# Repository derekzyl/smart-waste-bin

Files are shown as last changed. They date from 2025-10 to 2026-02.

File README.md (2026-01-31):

# Smart Waste Bin - IoT Waste Management System

A comprehensive IoT-based smart waste bin system that automatically detects material type (organic/non-organic) and manages waste segregation using ESP32 microcontrollers, ESP32-CAM for material detection, and a Flutter mobile app for control and monitoring.

## 🎯 Features

- **Motion Detection**: Automatically detects when someone approaches the bin
- **Material Classification**: Uses ESP32-CAM to classify waste as organic or non-organic
- **Automatic Bin Opening**: Opens the appropriate bin based on material type
- **Bin Level Monitoring**: Tracks bin fill level using ultrasonic sensors and load cells
- **Full Bin Protection**: Prevents opening when bins are full (except via app or keypad)
- **LED Indicators**: Visual feedback for bin status and fill level
- **Dual Communication**: WiFi communication with backend and direct ESP32 communication
- **Mobile App Control**: Full UI control via Flutter app
- **Backend API**: FastAPI backend for material detection and data management
- **Unique Bin IDs**: Each bin has a unique identifier for easy tracking

## 📋 System Architecture

```
┌─────────────────┐
│   Flutter App   │
│  (Mobile/Web)   │
└────────┬────────┘
         │
         ├───────────────────┐
         │                   │
    ┌────▼─────┐      ┌──────▼──────┐
    │  Backend │      │   ESP32     │
    │ (FastAPI)│      │   (Main)    │
    └──────────┘      └──────┬──────┘
                             │
                    ┌────────┴────────┐
                    │                 │
              ┌─────▼─────┐    ┌─────▼─────┐
              │ ESP32-CAM │    │  Sensors  │
              │ (Material │    │ & Actuators│
              │ Detection)│    └───────────┘
              └───────────┘
```

## 🔧 Hardware Components

### Core Components
- **ESP32-WROOM-32** (Main Controller)
- **ESP32-CAM** (Material Detection)
- **HC-SR04 Ultrasonic Sensor** (Distance/Bin Level)
- **Load Cell 5-10kg + HX711** (Weight Measurement)
- **SG90/MG996R Servo Motors** (Lid Control)
- **LEDs** (Red/Green/Blue for Status)
- **Piezo Buzzer** (Audio Feedback)
- **Tactile Buttons** (Keypad)

### Power Management
- **18650 Li-ion Cells** (2x for 7.4V)
- **TP4056 Charging Module**
- **MT3608 Boost Converter**
- **AMS1117-3.3V LDO**

See `smart_bin_design/` for PCB schematics.

## 📁 Project Structure

```
smart-waste-bin/
├── smart_waste_bin_firmware_/     # ESP32 Firmware
│   ├── src/
│   │   ├── main.cpp               # Main ESP32 firmware
│   │   └── esp32cam_main.cpp      # ESP32-CAM firmware
│   └── platformio.ini             # PlatformIO configuration
├── backend/                        # FastAPI Backend
│   ├── main.py                    # Backend API server
│   ├── requirements.txt           # Python dependencies
│   └── README.md                  # Backend documentation
├── smart_bin_app/                 # Flutter Mobile App
│   ├── lib/
│   │   ├── main.dart             # App entry point
│   │   ├── models/               # Data models
│   │   ├── services/             # API services
│   │   ├── providers/            # State management
│   │   ├── screens/              # UI screens
│   │   └── widgets/              # Reusable widgets
│   └── pubspec.yaml              # Flutter dependencies
└── smart_bin_design/              # KiCad PCB Design
```

## 🚀 Getting Started

### 1. ESP32 Firmware Setup

1. Install PlatformIO:
   ```bash
   pip install platformio
   ```

2. Configure WiFi credentials in `smart_waste_bin_firmware_/src/main.cpp`:
   ```cpp
   const char* ssid = "YOUR_WIFI_SSID";
   const char* password = "YOUR_WIFI_PASSWORD";
   const char* backend_url = "http://your-backend-url.com";
   ```

3. Upload firmware to ESP32:
   ```bash
   cd smart_waste_bin_firmware_
   pio run -e esp32dev -t upload
   ```

4. Upload ESP32-CAM firmware:
   ```bash
   pio run -e esp32cam -t upload
   ```

### 2. Backend Setup

1. Install Python dependencies:
   ```bash
   cd backend
   pip install -r requirements.txt
   ```

2. Run the backend server:
   ```bash
   python main.py
   ```
   
   Or with uvicorn:
   ```bash
   uvicorn main:app --host 0.0.0.0 --port 8000 --reload
   ```

3. The API will be available at `http://localhost:8000`
   - API Docs: `http://localhost:8000/docs`

### 3. Flutter App Setup

1. Install Flutter dependencies:
   ```bash
   cd smart_bin_app
   flutter pub get
   ```

2. Configure backend URL in the app settings (or default: `http://192.168.1.100:8000`)

3. Run the app:
   ```bash
   flutter run
   ```

## 📡 Communication Protocols

### ESP32 ↔ ESP32-CAM (CAN/TWAI)
- ESP32 sends: `DETECT_MATERIAL` request
- ESP32-CAM responds: `MATERIAL:ORGANIC` or `MATERIAL:NON_ORGANIC`

### ESP32 ↔ Backend (HTTP)
- POST `/api/bins/update` - Update bin status
- GET `/api/bins` - Get all bins status

### ESP32 ↔ Flutter App (WebSocket)
- Real-time bin status updates
- Commands: `open_organic`, `open_non_organic`, `close_*`, `get_status`

### ESP32-CAM ↔ Backend (HTTP)
- POST `/api/detect` - Material detection with image upload

## 🔌 Pin Configuration

### ESP32 Main Controller
### ESP32 Main Controller
- **Presence Ultrasonic**: TRIG=GPIO 4, ECHO=GPIO 5
- **Organic Level Ultrasonic**: TRIG=GPIO 25, ECHO=GPIO 26
- **Inorganic Level Ultrasonic**: TRIG=GPIO 32, ECHO=GPIO 33
- **Servos**: Organic=GPIO 18, Non-Organic=GPIO 19
- **Load Cell**: DOUT=GPIO 16, SCK=GPIO 17
- **LEDs Organic**: Red=GPIO 27, Green=GPIO 14
- **LEDs Inorganic**: Red=GPIO 12, Green=GPIO 13
- **Buzzer**: GPIO 15
- **Keypad**: Button1=GPIO 23, Button2=GPIO 2 (reassigned due to PIR removal)
- **CAN**: TX=GPIO 21, RX=GPIO 22

## 🎮 Usage

### Automatic Mode
1. Person approaches bin (PIR detects motion)
2. ESP32-CAM captures image and classifies material
3. Appropriate bin opens automatically
4. Bin closes after motion timeout

### Manual Mode (App/Keypad)
- Use Flutter app to open/close bins manually
- Use keypad buttons for quick access
- Maintenance mode available via app

### Bin Full Protection
- When bin reaches 90% capacity, it cannot be opened automatically
- Bins can still be opened via app or keypad for maintenance
- LED indicators show bin status (Red=Full, Yellow=High, Green=Normal)

## 🔐 Security & Configuration

- WiFi credentials stored in firmware 
- Backend API endpoints can be secured with authentication
- Bin IDs are unique identifiers for tracking

## 🧪 Testing

1. **Hardware Testing**: Test each sensor individually before full integration
2. **Material Detection**: Test with various waste types to improve classification
3. **Network Testing**: Verify WiFi connectivity and backend communication
4. **App Testing**: Test all app features on both WiFi and direct ESP32 connection

## 🤝 Contributing

1. Fork the repository
2. Create a feature branch
3. Make your changes
4. Submit a pull request

## 📄 License

This project is open source and available for educational and commercial use.

## 🙏 Acknowledgments

- ESP32 platform
- FastAPI framework
- Flutter framework
- OpenCV for image processing

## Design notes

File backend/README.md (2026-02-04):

# Smart Waste Bin Backend API

FastAPI backend for material detection and bin management with advanced image recognition.

## Features

- **Advanced Image Recognition**: Computer vision and ML-based material classification
- **Multiple Classification Methods**: ML model or rule-based fallback
- **Feature Extraction**: Comprehensive feature analysis (color, texture, shape, edges)
- **Model Training**: Script to train custom models on your data
- **RESTful API**: Easy-to-use endpoints for all operations

## Installation

```bash
pip install -r requirements.txt
```

## Running

```bash
python main.py
```

Or with uvicorn for development:

```bash
uvicorn main:app --host 0.0.0.0 --port 8000 --reload
```

The API will be available at `http://localhost:8000`
- API Docs: `http://localhost:8000/docs`
- Alternative Docs: `http://localhost:8000/redoc`

## Image Recognition System

### How It Works

The system uses a multi-feature approach for material classification:

1. **Color Analysis**: HSV color space, color histograms, dominant colors
2. **Texture Analysis**: Local Binary Patterns (LBP) for texture features
3. **Edge Detection**: Canny edge detection for shape analysis
4. **Contour Analysis**: Shape and circularity measurements
5. **Color Distribution**: Organic vs non-organic color indicators
6. **Color Diversity**: Entropy-based color variation analysis

### Classification Methods

#### 1. Machine Learning Model (Recommended)
- Uses Random Forest classifier
- Trained on labeled data
- Higher accuracy
- Requires training data

#### 2. Rule-Based Classifier (Default)
- Works out of the box
- No training required
- Good baseline accuracy
- Based on color and texture heuristics

### Training a Custom Model

1. **Prepare Training Data**:
   ```
   training_data/
     organic/
       image1.jpg
       image2.jpg
       ...
     non_organic/
       image1.jpg
       image2.jpg
       ...
   ```

2. **Run Training Script**:
   ```bash
   python train_model.py
   ```

3. **Use Trained Model**:
   - Set environment variable: `export MODEL_PATH=models/material_classifier.pkl`
   - Or update `main.py` to use the model path

## API Endpoints

### Material Detection

**POST** `/api/detect`
- Accepts: JPEG image file
- Returns: Classification result with material type and confidence

Example:
```bash
curl -X POST "http://localhost:8000/api/detect" \
  -F "file=@waste_image.jpg"
```

Response:
```json
{
  "material": "ORGANIC",
  "confidence": 0.85,
  "method": "ml_model",
  "probabilities": {
    "organic": 0.85,
    "non_organic": 0.15
  }
}
```

### Bin Management

- `GET /api/bins` - Get all bins status
- `GET /api/bins/{bin_id}` - Get specific bin status
- `POST /api/bins/update` - Update bin status from ESP32
- `POST /api/bins/{bin_id}/reset` - Reset bin (maintenance)
- `GET /api/stats` - Get overall statistics

## Configuration

### Environment Variables

- `MODEL_PATH`: Path to trained model file (default: `models/material_classifier.pkl`)
- `PORT`: Server port (default: 8000)
- `HOST`: Server host (default: 0.0.0.0)

### Model Performance

- **Rule-based**: ~70-75% accuracy
- **ML Model (trained)**: ~85-95% accuracy (depends on training data quality)

## Improving Accuracy

1. **Collect More Training Data**: More diverse images = better accuracy
2. **Image Quality**: Ensure good lighting and focus in training images
3. **Data Balance**: Equal number of organic and non-organic samples
4. **Augmentation**: Use data augmentation for better generalization
5. **Feature Engineering**: Add domain-specific features if needed

## Production Considerations

1. **Database**: Replace in-memory storage with PostgreSQL/MongoDB
2. **Model Versioning**: Track model versions and performance
3. **Caching**: Cache classification results for similar images
4. **Monitoring**: Add logging and performance monitoring
5. **Security**: Add authentication and rate limiting
6. **GPU Support**: Use GPU-accelerated TensorFlow for faster inference

## Troubleshooting

**Model not loading?**
- Check model file path
- Ensure joblib is installed
- Verify model file format

**Low accuracy?**
- Collect more training data
- Improve image quality
- Check for class imbalance
- Try different features or models

**Slow inference?**
- Use GPU acceleration
- Reduce image size
- Optimize feature extraction
- Use model quantization
# waste-bin-backend

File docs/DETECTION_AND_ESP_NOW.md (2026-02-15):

# Detection flow, app display, and ESP-NOW

## 1. Does the app show when someone opens a bin and the material?

**Yes**, when the conditions below are met.

### When the app is connected to the device (Settings → ESP32 IP set)

- The main ESP32 sends **WebSocket** messages to the app: `DETECTION_EVENT` with `action` and `material`/`confidence`.
- The app shows a **banner** at the top of the home screen:
  - **"Analyzing material..."** (orange, with spinner) while the bin is analyzing.
  - **"Organic (95%) — Opening bin"** or **"Non-organic (95%) — Opening bin"** (green) when a bin is opening, with the detected material and confidence.
  - **"Closing bin"** (grey) when the lid is closing.
- The banner hides automatically after about 4 seconds.
- So you do see **when** a bin is opening and **what material** was detected (organic vs non-organic and confidence %).

### When the app is not connected to a device (simulation / backend only)

- The app polls **`/api/detections?limit=1`** every 3 seconds and can show the **last detection** from the backend (material/confidence).
- When you tap **Open** (Organic or Non-organic), the app shows the same **"… — Opening bin"** banner for that choice.
- So in simulation you still see “opening” and “material” for the last detection and for manual open.

---

## 2. Why ESP-NOW might not work between ESP32-CAM and main devkit

ESP-NOW works only when both radios are on the **same 2.4 GHz channel** and addressing is correct. Typical causes of failure:

### A. WiFi channel mismatch (most common)

- **Main devkit**: Connects to WiFi (e.g. "cybergenii") and gets a channel (e.g. 6). It adds the CAM as peer with `channel = 0` (“use my current channel”).
- **ESP32-CAM**: Also uses STA mode. If it **connects to the same AP**, it usually gets the same channel and ESP-NOW can work. If it **doesn’t connect** (wrong password, no network, timeout), it may stay on a default channel (e.g. 1). Then:
  - Main sends on channel 6, CAM listens on channel 1 → **CAM never receives** → no trigger, no pairing.
  - So the first packet (Main → CAM) never arrives, and the CAM never learns the Main’s MAC to send the result back.

**What to do:** Ensure both devices use the same channel. E.g.:

- Confirm both connect to the same WiFi and check `WiFi.channel()` in Serial on both.
- Or set a fixed channel on both (e.g. `WiFi.begin(ssid, password, channel)` and use that same channel in `esp_now_peer_info_t.peer_info.channel` when adding the peer).

### B. Wrong ESP32-CAM MAC on the main

- The **main** has a **hardcoded** CAM MAC: `A0:DD:6C:AF:09:30` (in `main.cpp`).
- If your ESP32-CAM has a different MAC (different board, reflashed module), the main is sending to the wrong address and the CAM never receives.

**What to do:** On the ESP32-CAM, print its MAC at boot (e.g. `Serial.println(WiFi.macAddress());`). Update `camMacAddress[]` in the main firmware to that MAC.

### C. CAM never receives the first packet (so it never “pairs”)

- The **CAM** does **not** know the main’s MAC at compile time. It learns it only when it **receives** an ESP-NOW command (e.g. "DETECT") from the main and then adds that sender as a peer.
- If the main’s ESP-NOW send **fails** (channel/MAC as above), the CAM never receives, so:
  - `mainControllerRegistered` stays false,
  - When the CAM later runs detection (e.g. via **GPIO trigger**), it tries to send the result to an uninitialized or wrong MAC and **ESP-NOW send fails**.

So ESP-NOW can appear to “not work” in both directions: Main→CAM (trigger) and CAM→Main (result), often due to that first Main→CAM packet never arriving.

### D. Power / antenna

- ESP32-CAM can be power-hungry. Brown-out or unstable power can cause WiFi/ESP-NOW to fail.
- Poor antenna or metal enclosure can reduce range and make links unreliable.

### Summary

- **Most likely:** Channel mismatch (CAM not on same channel as main) or wrong CAM MAC on the main.
- **Check:** Serial on both sides: main “ESP-NOW Send Status: ✅/❌”, CAM “ESP-NOW Command Received” (or not), and `WiFi.channel()` on both. Fix channel and MAC first; then re-test.

---

## 3. How does polling work when an object is detected?

High-level flow:

1. **Presence**
   - Main ESP32 sees someone (ultrasonic presence sensor).
   - State goes **IDLE → DETECTING_MOTION**.

2. **Trigger camera**
   - Next loop: **DETECTING_MOTION → ANALYZING_MATERIAL**.
   - Main sends **"DETECT"** to the CAM via **ESP-NOW** and toggles **GPIO** (backup).
   - Main broadcasts **"ANALYZING"** on WebSocket so the app can show “Analyzing material...”.

3. **Camera and backend**
   - CAM captures image (triggered by ESP-NOW or GPIO).
   - CAM sends image to backend **POST /api/detect** (HTTPS).
   - Backend runs the classifier (e.g. Gemini), returns ORGANIC or NON_ORGANIC/INORGANIC, and **queues an OPEN command** in the DB for bin `0x001` (organic) or `0x002` (non-organic).

4. **Polling (main ESP32)**
   - While in **ANALYZING_MATERIAL**, the main ESP32 polls **every 100 ms** with a **single** request:
     - `GET /api/bins/commands` (returns pending commands for both bins).
   - Uses **HTTPS** (WiFiClientSecure).
   - Backend returns any pending commands for that bin and **removes** them from the queue (poll-once semantics).

5. **When OPEN is in the response**
   - Main parses the JSON (e.g. `command: "OPEN"`, `params: { material, confidence }`).
   - Main sets:
     - `currentState = OPENING_BIN`
     - `selectedBin = 0x001` or `0x002`
     - `openFromBackendCommand = true` (so the bin opens even if level sensors say “full”).
   - Main broadcasts **"OPENING"** on WebSocket with material and confidence so the app can show “Organic (95%) — Opening bin” (or non-organic).

6. **Opening the bin**
   - On the next loop iteration, the state machine runs **OPENING_BIN**:
     - Calls `openBin(0)` or `openBin(1)` (servo).
     - State goes to **BIN_OPEN** (lid stays open for a while, then auto-closes).

So **polling** is: the main MCU repeatedly asks the backend “any OPEN/CLOSE for 0x001 / 0x002?” every 250 ms while it’s waiting for the result. As soon as the backend has classified the image and queued OPEN, the next poll returns that command and the main opens the bin and notifies the app. No ESP-NOW or UART is required for this path.

---

## 4. Where does detection-to-open time go? (Latency)

| Phase | Typical time | Notes |
|---|---|---|
| Presence to trigger | 0–100 ms | Presence check every 100 ms. |
| Main to CAM trigger | 1–50 ms | ESP-NOW or GPIO. |
| **CAM capture + upload** | **0.5–2 s** | JPEG encode + HTTPS POST. |
| **Backend inference** | **1–4+ s** | Cloud API; usually the **largest** part. |
| Backend to queue | &lt; 50 ms | DB write. |
| Main polls and gets OPEN | 0–100 ms | Poll every 100 ms; single HTTPS GET. |
| Servo open | 50–200 ms | Physical. |

Most lag is **backend inference** and **image upload**. To reduce further: smaller image, faster model, or local inference.

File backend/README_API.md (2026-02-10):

# Energy Audit Backend API

## Overview
FastAPI extension for the Smart Energy Auditing System.
Integrated into the existing `smart-waste-bin` backend.

## New Endpoints (`/energy/...`)
-   `POST /energy/readings`: Accept sensor data from ESP32.
-   `GET /energy/readings/{id}`: Get stored readings.
-   `GET /energy/audit/{id}/alerts`: Get generated waste alerts.
-   `POST /energy/devices`: Register new devices.

## Setup
1.  Navigate to `backend/`.
2.  Install dependencies (if not already): `pip install -r requirements.txt`.
3.  Run Server:
    ```bash
    uvicorn main:app --reload --host 0.0.0.0
    ```
4.  Swagger Docs: `http://localhost:8000/docs`.

## Database
-   Tables `energy_devices`, `energy_sensor_readings`, etc., are created on startup.
-   Uses SQLite/PostgreSQL as configured in `database.py`.

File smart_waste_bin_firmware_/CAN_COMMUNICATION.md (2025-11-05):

# CAN Communication Guide

## Overview

The ESP32 and ESP32-CAM communicate via CAN (Controller Area Network) using ESP32's TWAI (Two-Wire Automotive Interface) protocol.

## Implementation Note

The current firmware uses simplified CAN message stubs. For production, you need to implement proper TWAI communication.

## Required Library

Add to `platformio.ini`:
```ini
lib_deps = 
    esp32-idf/twai
```

## CAN Message Format

### Request from ESP32 to ESP32-CAM
- **ID**: `0x100`
- **Data**: `"DETECT_MATERIAL"`
- **Purpose**: Request material detection

### Response from ESP32-CAM to ESP32
- **ID**: `0x200`
- **Data**: `"MATERIAL:ORGANIC"` or `"MATERIAL:NON_ORGANIC"` or `"MATERIAL:UNKNOWN"`
- **Purpose**: Send detection result

## Example TWAI Implementation

```cpp
#include "driver/twai.h"

void setupCAN() {
    twai_general_config_t g_config = TWAI_GENERAL_CONFIG_DEFAULT(
        GPIO_NUM_21,  // TX
        GPIO_NUM_22,  // RX
        TWAI_MODE_NORMAL
    );
    twai_timing_config_t t_config = TWAI_TIMING_CONFIG_500KBITS();
    twai_filter_config_t f_config = TWAI_FILTER_CONFIG_ACCEPT_ALL();
    
    ESP_ERROR_CHECK(twai_driver_install(&g_config, &t_config, &f_config));
    ESP_ERROR_CHECK(twai_start());
}

void sendCANMessage(uint32_t id, String message) {
    twai_message_t tx_msg;
    tx_msg.identifier = id;
    tx_msg.data_length_code = message.length();
    for (int i = 0; i < message.length() && i < 8; i++) {
        tx_msg.data[i] = message[i];
    }
    tx_msg.flags = TWAI_MSG_FLAG_NONE;
    twai_transmit(&tx_msg, pdMS_TO_TICKS(1000));
}

bool receiveCANMessage(uint32_t* id, String* message) {
    twai_message_t rx_msg;
    if (twai_receive(&rx_msg, pdMS_TO_TICKS(100)) == ESP_OK) {
        *id = rx_msg.identifier;
        *message = "";
        for (int i = 0; i < rx_msg.data_length_code; i++) {
            *message += (char)rx_msg.data[i];
        }
        return true;
    }
    return false;
}
```

## Testing

1. Connect ESP32 and ESP32-CAM via CAN bus (with proper termination resistors)
2. Test message transmission/reception
3. Verify material detection communication

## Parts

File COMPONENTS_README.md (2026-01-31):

# Smart Waste Bin - Components Reference

## Microcontrollers & Core Processing

### ESP32-WROOM-32
Main microcontroller that handles motion detection, sensor readings, servo control, WiFi communication, and system coordination.

### ESP32-CAM Module
Dedicated camera module that captures images for material classification and communicates detection results via CAN bus.

### USB-C or Micro-USB Breakout
Provides power input and programming interface for ESP32 development and firmware updates.

---

## Sensors

### HC-SR04 Ultrasonic Sensor (Presence Detection)
Replaces the PIR sensor to detect when a person is approaching the bin to trigger the system.

### JSN-SR04T Waterproof Ultrasonic Sensor (x2)
Two waterproof sensors used to measure the fill levels of the Organic and Non-Organic bins independently.

### Load Cell (5kg or 10kg)
Measures the weight of waste in the bin using strain gauge technology.

### HX711 Load Cell Amplifier Module
Amplifies and converts analog load cell signals into digital data readable by the ESP32.

---

## Actuators & Feedback

### MG996R Servo Motor (Alternative)
Heavy-duty servo motor capable of handling bin lids up to 1.5kg with higher torque.

### 5mm LED (2x Red, 2x Green)
- **2x Red**: Indicate when the Organic or Non-Organic bin is full.
- **2x Green**: Indicate that the Organic or Non-Organic bin has space available.

### Piezo Buzzer (Active 3-5V)
Provides audio feedback for bin operations, alerts, and warnings.

### Tactile Push Button (6×6mm)
Manual override buttons for opening bins when automatic system is unavailable or for maintenance.

---

## Power Management

### 18650 Li-ion Cell (3000-3500mAh)
Rechargeable battery cells providing 3.7V power source for portable operation.

### MT3608 Boost Converter (2A, Adjustable)
Steps up battery voltage to 5V for powering servos and other 5V components.

### XL6009 Boost Module (Alternative)
Alternative boost converter module with higher current capacity for power-hungry applications.

### AMS1117-3.3V LDO Regulator
Provides stable 3.3V power supply for ESP32 and other low-voltage components from higher voltage sources.

### Mini360 Buck Converter (Alternative)
DC-DC step-down converter alternative for efficiently reducing voltage to 3.3V.

---

## Circuit Components

### Capacitors

#### 0.1µF (100nF) Ceramic Capacitor (X7R, 50V) - 6 pcs
Decoupling capacitors that filter high-frequency noise from power supply lines to prevent interference.

#### 1µF Ceramic Capacitor (X7R, 50V) - 3 pcs
Filters noise and stabilizes voltage for analog sensor inputs.

#### 10µF Ceramic Capacitor (X5R/X7R, 25V) - 2 pcs
Provides output stability for voltage regulators and prevents oscillation.

#### 100µF Electrolytic Capacitor (Low-ESR, 25V) - 2 pcs
Bulk capacitance that smooths power supply fluctuations and handles current surges.

#### 470µF Electrolytic Capacitor (Low-ESR, 16V) - 1 pc
Optional motor surge protection capacitor that absorbs voltage spikes from servo operation.

### Resistors (1/4W, 5% tolerance)

#### 10kΩ Resistor - 5 pcs
Pull-up resistors for digital inputs like buttons and I2C communication lines.

#### 330Ω Resistor - 3 pcs
Current-limiting resistors that protect LEDs from excessive current draw.

#### 4.7kΩ Resistor - 2 pcs
I2C bus pull-up resistors for reliable communication with external modules.

### Other Passive Components

#### Ferrite Bead (600Ω @ 100MHz) - 2 pcs
Filters electromagnetic interference from power supply lines to reduce noise.

#### Schottky Diode 1N5819 (1A) - 2 pcs
Provides reverse polarity protection and flyback diode protection for servo motors.

---

## Connectors & Wiring

### JST-XH 2.54mm Connectors (2-pin, 3-pin, 4-pin)
Standardized connectors for reliable, removable connections between PCBs and components.

### DuPont Jumper Wires (M-M, M-F, F-F)
Flexible prototyping wires for connecting components during development and testing.

### 22 AWG Silicone Wire (Red/Black) - 2m each
Flexible power and ground wires with high-temperature resistance for permanent installations.

### Heat Shrink Tubing (Assorted Sizes)
Protective insulation that shrinks when heated to secure and insulate wire connections.

---

## Enclosure & Mechanical

### Servo Horn/Arm
Attaches to servo motor shaft to connect with bin lid mechanism for opening/closing action.

### M2/M3 Screws and Nuts
Hardware for assembling the physical structure and mounting components securely.

### Plastic Hinges (Small)
Allows bin lids to pivot smoothly when opened and closed by servo motors.

### Cable Glands or Grommets (6-10mm)
Provides waterproof cable entry points in the enclosure for outdoor installations.

---

## Optional Add-ons

### SIM800L GSM Module
Enables SMS alerts and remote monitoring without WiFi connection using cellular network.

### PN532 NFC/RFID Reader Module
Adds access control functionality for authorized users via NFC cards or RFID tags.

### 6V 1W Solar Panel + TP4056 Solar Charge Controller
Provides renewable energy charging for outdoor installations with sunlight exposure.

---

## Component Summary by Category

| Category | Component Count | Purpose |
|---|---|---|
| Microcontrollers | 2 | System control and processing |
| Sensors | 5 | Detection and measurement |
| Actuators | 5 | Movement and feedback |
| Power Management | 6 | Battery and power regulation |
| Passive Components | ~20 | Circuit protection and filtering |
| Connectors | Assorted | Interconnections |
| Mechanical | Assorted | Physical assembly |

---

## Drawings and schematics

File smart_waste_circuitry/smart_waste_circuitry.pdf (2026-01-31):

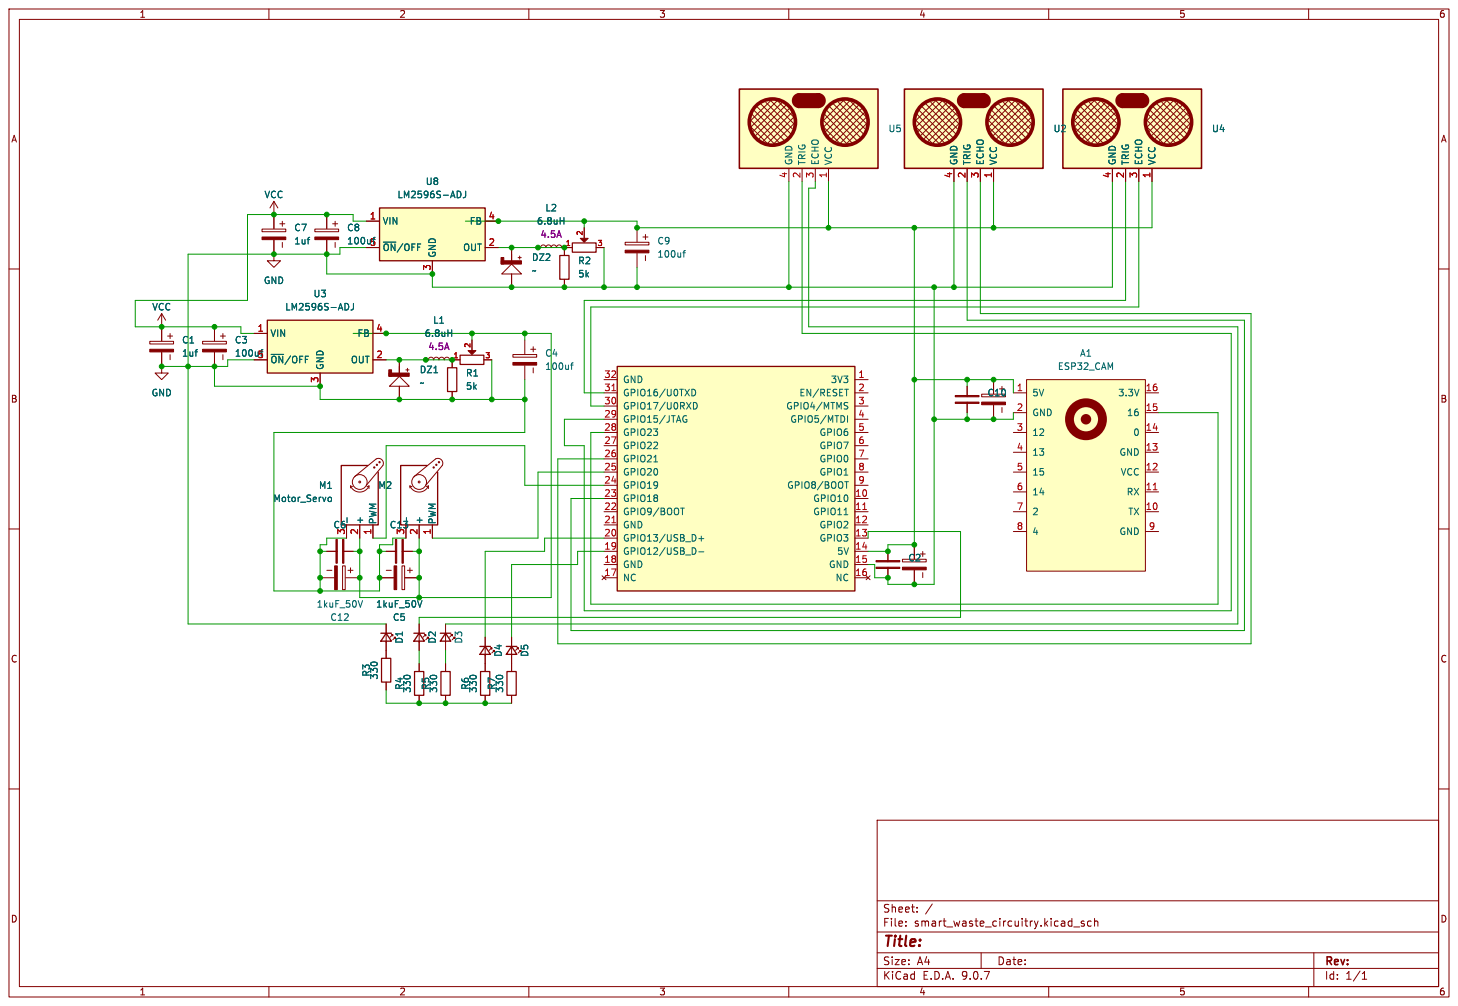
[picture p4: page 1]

Id: 1/1 Title: File: smart_waste_circuitry.kicad_sch Sheet: /

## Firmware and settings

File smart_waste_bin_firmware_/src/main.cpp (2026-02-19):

/**
 * ESP32 Smart Waste Bin - ESP-NOW CONNECTION FIX
 * ESP32-CAM MAC: A0:DD:6C:AF:09:30
 */

#include <Arduino.h>
#include <WiFi.h>
#include <esp_now.h>
#include <ESPAsyncWebServer.h>
#include <ArduinoJson.h>
#include <Adafruit_PWMServoDriver.h> // REPLACES ESP32Servo
#include <WebSocketsServer.h>
#include <HTTPClient.h>
#include <WiFiClientSecure.h>

// ==================== PIN DEFINITIONS ====================
#define TRIG_PIN_PRESENCE 32
#define ECHO_PIN_PRESENCE 34
#define TRIG_PIN_ORG 33
#define ECHO_PIN_ORG 35
#define TRIG_PIN_INORG 13
#define ECHO_PIN_INORG 36



// PCA9685 SERVO CONFIG
#define SERVOMIN  150 // This is the 'minimum' pulse length count (out of 4096)
#define SERVOMAX  600 // This is the 'maximum' pulse length count (out of 4096)
#define USMIN  600 // This is the rounded 'minimum' microsecond length based on the minimum pulse of 150
#define USMAX  2400 // This is the rounded 'maximum' microsecond length based on the maximum pulse of 600
#define SERVO_FREQ 50 // Analog servos run at ~50 Hz updates

// Channels on PCA9685 (0 to 15)
#define PCA_CHANNEL_ORG 0
#define PCA_CHANNEL_INORG 1

// I2C Pins for PCA9685
#define I2C_SDA 21
#define I2C_SCL 22

#define CAM_TRIGGER_PIN 4

#define LED_ORG_RED_PIN 25
#define LED_ORG_GREEN_PIN 26
#define LED_INORG_RED_PIN 27
#define LED_INORG_GREEN_PIN 14

#define UART_RX_PIN 15
#define UART_BAUD 115200

// ==================== CONFIGURATION ====================
const char* ssid = "cybergenii";
const char* password = "12341234";
const char* backend_url = "https://xenophobic-netta-cybergenii-1584fde7.koyeb.app";
const char* local_access_password = "SmartBin2025";

const char* BIN_ORGANIC_ID = "0x001";
const char* BIN_NON_ORGANIC_ID = "0x002";
const float MAX_BIN_HEIGHT_CM = 91.44;  // 3 feet
const float BIN_FULL_THRESHOLD_CM = 10.0;
const float SENSOR_OFFSET_CM = 5.0;

// ==================== ESP-NOW CONFIGURATION ====================
// ESP32-CAM MAC Address: A0:DD:6C:AF:09:30
uint8_t camMacAddress[] = { 
  0xA0, 0xDD, 0x6C, 0xAF, 0x09, 0x30 
};

bool espNowInitialized = false;
bool camPeerAdded = false;
int espNowSendCount = 0;
int espNowReceiveCount = 0;
int espNowFailCount = 0;

// ESP-NOW Message Structures
typedef struct {
  char command[32];
  unsigned long timestamp;
} CommandMessage;

typedef struct {
  char material[32];
  float confidence;
  unsigned long timestamp;
} DetectionResult;

// ==================== GLOBAL VARIABLES ====================
Adafruit_PWMServoDriver pwm = Adafruit_PWMServoDriver(); // Default address 0x40

// ==================== NEWPING SENSOR SETUP ====================
#include <NewPing.h>

#define MAX_DISTANCE 200 // Maximum distance we want to ping for (in centimeters).

// Sensor Objects
NewPing sonarPresence(TRIG_PIN_PRESENCE, ECHO_PIN_PRESENCE, MAX_DISTANCE);
NewPing sonarOrganic(TRIG_PIN_ORG, ECHO_PIN_ORG, MAX_DISTANCE);
NewPing sonarInorganic(TRIG_PIN_INORG, ECHO_PIN_INORG, MAX_DISTANCE);

// Helper to get median distance (filters noise)
float getFilteredDistance(NewPing &sonar) {
  unsigned int uS = sonar.ping_median(5); // Take 5 readings and return median
  float dist = sonar.convert_cm(uS);
  if (dist == 0) return -1.0; // Timeout or out of range
  return dist;
}

AsyncWebServer server(80);
WebSocketsServer webSocket(81);

enum BinState {
  IDLE,
  DETECTING_MOTION,
  ANALYZING_MATERIAL,
  OPENING_BIN,
  BIN_OPEN,
  CLOSING_BIN
};

BinState currentState = IDLE;
String selectedBin = "";

float organicBinLevelCm = 0.0;
float nonOrganicBinLevelCm = 0.0;
int organicBinLevelPct = 0;
int nonOrganicBinLevelPct = 0;
bool isOrganicBinFull = false;
bool isNonOrganicBinFull = false;

unsigned long lastMotionTime = 0;
unsigned long binOpenTime = 0;
const unsigned long MOTION_TIMEOUT = 5000;
const unsigned long BIN_OPEN_TIMEOUT = 10000;
unsigned long lastLevelCheckTime = 0;
const unsigned long LEVEL_CHECK_INTERVAL = 2000;

unsigned long lastBackendSyncTime = 0;
const unsigned long BACKEND_SYNC_INTERVAL = 5000;
unsigned long lastCommandPollTime = 0;
const unsigned long COMMAND_POLL_INTERVAL = 800;   // Normal: poll every 800ms
const unsigned long COMMAND_POLL_FAST_MS = 100;    // When analyzing: poll every 100ms for low latency

const float PRESENCE_THRESHOLD_CM = 50.0;
const int PRESENCE_DEBOUNCE_COUNT = 3;

String detectedMaterial = "";
float detectedConfidence = 0.0;
bool materialDetectionComplete = false;
unsigned long materialDetectionStartTime = 0;
const unsigned long MATERIAL_DETECTION_TIMEOUT = 15000;  // Increased to 15s

bool presenceDetectedForChase = false;
unsigned long lastChaseUpdate = 0;
const unsigned long CHASE_SPEED = 100;
int chasePosition = 0;

// When true, OPENING_BIN will open the bin even if level sensors say "full" (backend command)
bool openFromBackendCommand = false;
const int LED_PINS[] = {LED_ORG_GREEN_PIN, LED_ORG_RED_PIN, LED_INORG_GREEN_PIN, LED_INORG_RED_PIN};
const int NUM_LEDS = 4;

// ==================== FUNCTION DECLARATIONS ====================
void setupWiFi();
void setupESPNow();
void setupWebServer();
void setupWebSocket();
void setupUART();
void openBin(uint8_t binType);
void closeBin(uint8_t binType);
void updateBinLevels();
void updateLEDs();
void sendBinDataToBackend();
void webSocketEvent(uint8_t num, WStype_t type, uint8_t * payload, size_t length);

void triggerCameraDetection();
void processUARTData();
bool authenticateRequest(AsyncWebServerRequest *request);
void sendWebSocketStatus(uint8_t clientNum);
void handleWebSocketMessage(uint8_t clientNum, String message);
void runLEDChaseMode();
void testAllLEDs();
void testAllSensors();
void onDataRecv(const uint8_t *mac, const uint8_t *incomingData, int len);
void onDataSent(const uint8_t *mac, esp_now_send_status_t status);
void sendESPNowCommand(const char* cmd);
void sendESPNowCommand(const char* cmd);
void testESPNowConnection();
void pollBackendCommands();
int angleToPulse(int angle);
void setServoAngle(uint8_t channel, int angle);
void broadcastDetectionEvent(String material, float confidence, String action);

// ==================== SETUP ====================
void setup() {
  Serial.begin(115200);
  delay(2000);

  Serial.println("\n\n=================================");
  Serial.println("ESP32 Main Controller");
  Serial.println("ESP-NOW + Waterproof Sensors");
  Serial.println("=================================");

  // Initialize pins
  pinMode(TRIG_PIN_PRESENCE, OUTPUT);
  pinMode(ECHO_PIN_PRESENCE, INPUT);
  pinMode(TRIG_PIN_ORG, OUTPUT);
  pinMode(ECHO_PIN_ORG, INPUT);
  pinMode(TRIG_PIN_INORG, OUTPUT);
  pinMode(ECHO_PIN_INORG, INPUT);

  pinMode(LED_ORG_RED_PIN, OUTPUT);
  pinMode(LED_ORG_GREEN_PIN, OUTPUT);
  pinMode(LED_INORG_RED_PIN, OUTPUT);
  pinMode(LED_INORG_GREEN_PIN, OUTPUT);

  pinMode(CAM_TRIGGER_PIN, OUTPUT);
  digitalWrite(CAM_TRIGGER_PIN, LOW);

  pinMode(CAM_TRIGGER_PIN, OUTPUT);
  digitalWrite(CAM_TRIGGER_PIN, LOW);

  // Initialize I2C for PCA9685
  Wire.begin(I2C_SDA, I2C_SCL);
  
  // Initialize PCA9685
  Serial.println("Initializing PCA9685 Servo Controller on 0x40...");
  pwm.begin();
  pwm.setOscillatorFrequency(27000000);
  pwm.setPWMFreq(SERVO_FREQ);  // Analog servos run at ~50 Hz updates
  delay(10);

  // Reset Servos (Close)
  setServoAngle(PCA_CHANNEL_ORG, 0);
  setServoAngle(PCA_CHANNEL_INORG, 0);

  // LED TEST
  Serial.println("\n>>> LED TEST <<<");
  testAllLEDs();

  // Initialize WiFi FIRST (required for ESP-NOW)
  setupWiFi();

  // CRITICAL: WiFi must be initialized before ESP-NOW
  if (WiFi.status() == WL_CONNECTED || WiFi.getMode() == WIFI_STA) {
    setupESPNow();
  } else {
    Serial.println("⚠️  WiFi not initialized - ESP-NOW may fail");
    // Force WiFi STA mode
    WiFi.mode(WIFI_STA);
    WiFi.disconnect();
    delay(100);
    setupESPNow();
  }

  // SENSOR TEST
  Serial.println("\n>>> SENSOR TEST <<<");
  testAllSensors();

  // Test ESP-NOW connection
  Serial.println("\n>>> ESP-NOW CONNECTION TEST <<<");
  testESPNowConnection();

  setupUART();
  setupWebServer();
  setupWebSocket();

  Serial.println("\n=================================");
  Serial.println("SYSTEM READY");
  Serial.println("=================================");
  
  Serial.print("ESP32 Main MAC: ");
  Serial.println(WiFi.macAddress());
  
  Serial.print("ESP32-CAM MAC: ");
  for (int i = 0; i < 6; i++) {
    Serial.printf("%02X", camMacAddress[i]);
    if (i < 5) Serial.print(":");
  }
  Serial.println();
  
  Serial.print("Local IP: ");
  Serial.println(WiFi.localIP());
  
  Serial.println("\n📡 ESP-NOW Status:");
  Serial.println("  Initialized: " + String(espNowInitialized ? "✅" : "❌"));
  Serial.println("  Peer Added: " + String(camPeerAdded ? "✅" : "❌"));
  Serial.println("  WiFi Channel: " + String(WiFi.channel()));
  
  Serial.println("\n🔍 Waiting for presence detection...");
  Serial.println("=================================\n");

  updateLEDs();
}

// ==================== ESP-NOW SETUP ====================
void setupESPNow() {
  Serial.println("\nInitializing ESP-NOW...");
  
  // Ensure WiFi is in STA mode
  if (WiFi.getMode() != WIFI_STA) {
    Serial.println("  Setting WiFi to STA mode...");
    WiFi.mode(WIFI_STA);
    delay(100);
  }

  // Initialize ESP-NOW
  if (esp_now_init() != ESP_OK) {
    Serial.println("  ❌ ESP-NOW init FAILED");
    espNowInitialized = false;
    return;
  }

  espNowInitialized = true;
  Serial.println("  ✓ ESP-NOW initialized");

  // Register callbacks
  esp_now_register_send_cb(onDataSent);
  esp_now_register_recv_cb(onDataRecv);
  Serial.println("  ✓ Callbacks registered");

  // Add ESP32-CAM as peer
  esp_now_peer_info_t peerInfo = {};
  memcpy(peerInfo.peer_addr, camMacAddress, 6);
  peerInfo.channel = 0;  // Use current WiFi channel (auto)
  peerInfo.encrypt = false;
  peerInfo.ifidx = WIFI_IF_STA;

  if (esp_now_add_peer(&peerInfo) != ESP_OK) {
    Serial.println("  ❌ Failed to add ESP32-CAM peer");
    camPeerAdded = false;
  } else {
    Serial.println("  ✓ ESP32-CAM peer added successfully");
    Serial.print("  Peer MAC: ");
    for (int i = 0; i < 6; i++) {
      Serial.printf("%02X", camMacAddress[i]);
      if (i < 5) Serial.print(":");
    }
    Serial.println();
    camPeerAdded = true;
  }
}

// ==================== ESP-NOW CALLBACKS ====================
void onDataSent(const uint8_t *mac, esp_now_send_status_t status) {
  Serial.print("\n📡 ESP-NOW Send Status: ");
  
  if (status == ESP_NOW_SEND_SUCCESS) {
    Serial.println("✅ SUCCESS");
    espNowSendCount++;
  } else {
    Serial.println("❌ FAILED");
    espNowFailCount++;
    
    // Detailed error info
    Serial.println("  Possible causes:");
    Serial.println("  - ESP32-CAM not powered on");
    Serial.println("  - ESP32-CAM WiFi not initialized");
    Serial.println("  - Different WiFi channels");
    Serial.println("  - Out of range");
  }
  
  Serial.printf("  Stats: Sent=%d, Failed=%d\n", espNowSendCount, espNowFailCount);
}

void onDataRecv(const uint8_t *mac, const uint8_t *incomingData, int len) {
  espNowReceiveCount++;
  
  Serial.println("\n📡 ESP-NOW Data Received!");
  Serial.print("  From MAC: ");
  for (int i = 0; i < 6; i++) {
    Serial.printf("%02X", mac[i]);
    if (i < 5) Serial.print(":");
  }
  Serial.println();
  Serial.printf("  Length: %d bytes\n", len);

  if (len == sizeof(DetectionResult)) {
    DetectionResult result;
    memcpy(&result, incomingData, sizeof(result));

    detectedMaterial = String(result.material);
    detectedConfidence = result.confidence;

    Serial.println("  ✅ Parsed Detection Result:");
    Serial.printf("    Material: %s\n", detectedMaterial.c_str());
    Serial.printf("    Confidence: %.2f%%\n", detectedConfidence * 100);

    materialDetectionComplete = true;
  } else {
    Serial.printf("  ⚠️  Unexpected data length: %d (expected %d)\n", len, sizeof(DetectionResult));
  }
}

void sendESPNowCommand(const char* cmd) {
  if (!espNowInitialized) {
    Serial.println("⚠️  ESP-NOW not initialized - cannot send");
    return;
  }
  
  if (!camPeerAdded) {
    Serial.println("⚠️  ESP32-CAM peer not added - cannot send");
    return;
  }

  CommandMessage message;
  strncpy(message.command, cmd, sizeof(message.command) - 1);
  message.command[sizeof(message.command) - 1] = '\0';
  message.timestamp = millis();

  Serial.printf("\n📡 Sending ESP-NOW command: %s\n", cmd);
  
  esp_err_t result = esp_now_send(camMacAddress, (uint8_t *)&message, sizeof(message));

  if (result == ESP_OK) {
    Serial.println("  ✓ Command queued for sending");
  } else {
    Serial.printf("  ❌ Send failed with error: %d\n", result);
    
    // Try GPIO fallback
    Serial.println("  → Using GPIO fallback");
    digitalWrite(CAM_TRIGGER_PIN, HIGH);
    delay(100);
    digitalWrite(CAM_TRIGGER_PIN, LOW);
  }
}

void testESPNowConnection() {
  if (!espNowInitialized || !camPeerAdded) {
    Serial.println("  ⚠️  ESP-NOW not ready - skipping test");
    return;
  }
  
  Serial.println("  Sending test message to ESP32-CAM...");
  sendESPNowCommand("TEST");
  
  Serial.println("  Waiting 2 seconds for response...");
  delay(2000);
  
  if (espNowReceiveCount > 0) {
    Serial.println("  ✅ ESP-NOW connection working!");
  } else {
    Serial.println("  ⚠️  No response from ESP32-CAM");
    Serial.println("  Check:");
    Serial.println("    - ESP32-CAM is powered on");
    Serial.println("    - ESP32-CAM code is running");
    Serial.println("    - Both devices on same WiFi channel");
  }
}



// ==================== WEBSOCKET BROADCAST ====================
void broadcastDetectionEvent(String material, float confidence, String action) {
  // Create JSON message for App
  DynamicJsonDocument doc(512);
  doc["type"] = "DETECTION_EVENT";
  doc["material"] = material;
  doc["confidence"] = confidence;
  doc["action"] = action; // "OPENING" or "CLOSING"

  String jsonString;
  serializeJson(doc, jsonString);
  
  // Broadcast to all connected WebSocket clients (The App)
  webSocket.broadcastTXT(jsonString);
  Serial.println("📡 WebSocket Broadcast: " + jsonString);
}


// ==================== MAIN LOOP ====================
void loop() {
  webSocket.loop();
  processUARTData();

  // Presence detection (100ms for faster reaction)
  static unsigned long lastPresenceCheck = 0;
  if (millis() - lastPresenceCheck >= 100) {
    float distance = getFilteredDistance(sonarPresence); // Uses median filter

    if (distance > 0 && distance < PRESENCE_THRESHOLD_CM) {
      if (!presenceDetectedForChase) {
        presenceDetectedForChase = true;
        Serial.println("\n🎯 PRESENCE DETECTED!");
        Serial.printf("   Distance: %.2f cm\n", distance);
        
        // Trigger camera
        if (currentState == IDLE) {
          currentState = DETECTING_MOTION;
        }
      }
    } else {
      if (presenceDetectedForChase) {
        presenceDetectedForChase = false;
        Serial.println("\n✋ Presence lost\n");
        for (int i = 0; i < NUM_LEDS; i++) {
          digitalWrite(LED_PINS[i], LOW);
        }
      }
    }

    lastPresenceCheck = millis();
  }

  // LED chase
  if (presenceDetectedForChase) {
    runLEDChaseMode();
  } else {
    updateLEDs();
  }

  // Update bin levels
  if (millis() - lastLevelCheckTime > LEVEL_CHECK_INTERVAL) {
    updateBinLevels();
    
    static int readingCount = 0;
    if (readingCount++ % 10 == 0) {
      Serial.println("\n📊 Sensor Readings:");
      Serial.printf("   Presence:  %.2f cm\n", getFilteredDistance(sonarPresence));
      Serial.printf("   Organic:   %.2f cm (%d%%)\n", organicBinLevelCm, organicBinLevelPct);
      Serial.printf("   Inorganic: %.2f cm (%d%%)\n", nonOrganicBinLevelCm, nonOrganicBinLevelPct);
      Serial.printf("   ESP-NOW: Sent=%d, Received=%d, Failed=%d\n", 
                    espNowSendCount, espNowReceiveCount, espNowFailCount);
    }

    lastLevelCheckTime = millis();
  }

  // Poll for commands from Backend - aggressive when waiting for cloud result
  unsigned long pollInterval = (currentState == ANALYZING_MATERIAL)
    ? COMMAND_POLL_FAST_MS
    : COMMAND_POLL_INTERVAL;
  if (millis() - lastCommandPollTime > pollInterval) {
    pollBackendCommands();
    lastCommandPollTime = millis();
  }

  // State Machine
  switch (currentState) {
    case IDLE:
      // Allow unsolicited results (e.g. from Web UI or manual trigger)
      if (materialDetectionComplete) {
        Serial.println("\n>>> Unsolicited detection result received!");
        
        if (detectedMaterial == "ORGANIC") {
          selectedBin = BIN_ORGANIC_ID;
          Serial.println(">>> Opening organic bin");
          currentState = OPENING_BIN;
        } else if (detectedMaterial == "NON_ORGANIC" || detectedMaterial == "INORGANIC") {
          selectedBin = BIN_NON_ORGANIC_ID;
          Serial.println(">>> Opening inorganic bin");
          currentState = OPENING_BIN;
        } else {
          Serial.println(">>> UNKNOWN material - ignoring");
        }
        
        materialDetectionComplete = false;
      }
      break;

    case DETECTING_MOTION:
      currentState = ANALYZING_MATERIAL;
      materialDetectionStartTime = millis();
      triggerCameraDetection();
      broadcastDetectionEvent("", 0.0f, "ANALYZING");
      break;

    case ANALYZING_MATERIAL:
      if (materialDetectionComplete) {
        if (detectedMaterial == "ORGANIC") {
          selectedBin = BIN_ORGANIC_ID;
          Serial.println(">>> Opening organic bin");
        } else if (detectedMaterial == "NON_ORGANIC" || detectedMaterial == "INORGANIC") {
          selectedBin = BIN_NON_ORGANIC_ID;
          Serial.println(">>> Opening inorganic bin");
        } else {
          Serial.println(">>> UNKNOWN material");
          currentState = IDLE;
          break;
        }

        broadcastDetectionEvent(detectedMaterial, detectedConfidence, "OPENING");
        currentState = OPENING_BIN;
        materialDetectionComplete = false;
      }

      if (millis() - materialDetectionStartTime > MATERIAL_DETECTION_TIMEOUT) {
        Serial.println(">>> Detection TIMEOUT");
        currentState = IDLE;
        materialDetectionComplete = false;
      }
      break;

    case OPENING_BIN: {
      // Backend/cloud command: always open (bypass full check so detection always opens bin)
      bool allowOpen = openFromBackendCommand ||
        (selectedBin == BIN_ORGANIC_ID && !isOrganicBinFull) ||
        (selectedBin == BIN_NON_ORGANIC_ID && !isNonOrganicBinFull);
      openFromBackendCommand = false;

      if (selectedBin == BIN_ORGANIC_ID) {
        if (allowOpen) {
          Serial.println(">>> Executing OPEN: organic bin (servo)");
          openBin(0);
          currentState = BIN_OPEN;
          binOpenTime = millis();
          lastMotionTime = millis();
        } else {
          Serial.println("❌ ORGANIC BIN FULL - Staying Closed");
          currentState = IDLE;
        }
      } else if (selectedBin == BIN_NON_ORGANIC_ID) {
        if (allowOpen) {
          Serial.println(">>> Executing OPEN: inorganic bin (servo)");
          openBin(1);
          currentState = BIN_OPEN;
          binOpenTime = millis();
          lastMotionTime = millis();
        } else {
          Serial.println("❌ INORGANIC BIN FULL - Staying Closed");
          currentState = IDLE;
        }
      } else {
        Serial.println("❌ Unknown bin selected");
        currentState = IDLE;
      }
      break;
    }

    case BIN_OPEN:
      {
        // Extend open time if motion detected (someone is still throwing trash)
        float distance = getFilteredDistance(sonarPresence);
        if (distance > 0 && distance < PRESENCE_THRESHOLD_CM) {
          lastMotionTime = millis();
          Serial.println("  User present - extending open time");
        }

        // Auto Close Logic
        // Close if:
        // 1. No motion for MOTION_TIMEOUT (5s)
        // 2. OR Absolute max time of BIN_OPEN_TIMEOUT (10s) reached
        unsigned long timeSinceMotion = millis() - lastMotionTime;
        unsigned long timeSinceOpen = millis() - binOpenTime;
        
        if (timeSinceMotion > MOTION_TIMEOUT || timeSinceOpen > BIN_OPEN_TIMEOUT) {
          Serial.println(">>> Auto-closing bin...");
          currentState = CLOSING_BIN;
        }
      }
      break;

    case CLOSING_BIN:
      if (selectedBin == BIN_ORGANIC_ID) {
        closeBin(0);
      } else {
        closeBin(1);
      }
      broadcastDetectionEvent(
        selectedBin == BIN_ORGANIC_ID ? "ORGANIC" : "NON_ORGANIC",
        0.0f,
        "CLOSING"
      );
      Serial.println(">>> Bin Closed. Returning to IDLE\n");
      currentState = IDLE;
      break;
  }

  delay(10);
}

// ==================== CAMERA TRIGGER ====================
void triggerCameraDetection() {
  Serial.println("\n>>> TRIGGERING CAMERA <<<");
  
  // ESP-NOW (primary)
  sendESPNowCommand("DETECT");
  
  // GPIO (backup)
  digitalWrite(CAM_TRIGGER_PIN, HIGH);
  delay(100);
  digitalWrite(CAM_TRIGGER_PIN, LOW);
  
  Serial.println("  ✓ Trigger sent via ESP-NOW + GPIO");
}

// ==================== BIN LEVEL MONITORING ====================


// ==================== SENSOR TEST ====================
void testAllSensors() {
  Serial.println("  Testing sensors (NewPing Median Filter):\n");
  
  Serial.println("  PRESENCE:");
  float dist = getFilteredDistance(sonarPresence);
  Serial.printf("    Distance: %.2f cm\n", dist);
  
  Serial.println("\n  ORGANIC BIN (AJ-SR04M / SR04M-2):");
  dist = getFilteredDistance(sonarOrganic);
  if (dist == -1) Serial.println("    Result: Timeout / Blind Spot");
  else Serial.printf("    Result: %.2f cm\n", dist);
  
  Serial.println("\n  INORGANIC BIN (AJ-SR04M / SR04M-2):");
  dist = getFilteredDistance(sonarInorganic);
  if (dist == -1) Serial.println("    Result: Timeout / Blind Spot");
  else Serial.printf("    Result: %.2f cm\n", dist);
  
  Serial.println("\n  ✓ Sensor test complete\n");
}
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

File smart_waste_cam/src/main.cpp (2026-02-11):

/**
 * ESP32-CAM Material Detection - COMPLETE WIRELESS VERSION
 * 
 * Features:
 * - ESP-NOW wireless communication with ESP32 Main
 * - GPIO trigger input (backup/redundant)
 * - UART TX output (backup)
 * - WiFi backend integration
 * - Boot-safe pin configuration
 * 
 * Pin Configuration:
 * - UART TX: GPIO 14 (SD CLK - safe if SD unused)
 * - Trigger: GPIO 13 (SD D3 - boot-safe)
 * 
 * Communication Priority:
 * 1. ESP-NOW (wireless) - Primary
 * 2. GPIO Trigger - Backup
 * 3. UART TX - Backup response
 */

#include <Arduino.h>
#include <WiFi.h>
#include <esp_now.h>
#include <ESPAsyncWebServer.h>
#include <ArduinoJson.h>
#include "esp_camera.h"
#include <WebSocketsServer.h>
#include <HTTPClient.h>
#include <WiFiClientSecure.h>

// ==================== CAMERA PINS ====================
#define PWDN_GPIO_NUM     32
#define RESET_GPIO_NUM    -1
#define XCLK_GPIO_NUM      0
#define SIOD_GPIO_NUM     26
#define SIOC_GPIO_NUM     27
#define Y9_GPIO_NUM       35
#define Y8_GPIO_NUM       34
#define Y7_GPIO_NUM       39
#define Y6_GPIO_NUM       36
#define Y5_GPIO_NUM       21
#define Y4_GPIO_NUM       19
#define Y3_GPIO_NUM       18
#define Y2_GPIO_NUM        5
#define VSYNC_GPIO_NUM    25
#define HREF_GPIO_NUM     23
#define PCLK_GPIO_NUM     22

// ==================== COMMUNICATION PINS ====================
// UART TX - GPIO 14 (SD CLK - safe if SD unused)
#define UART_TX_PIN       14

// Trigger Input - GPIO 13 (SD D3 - boot-safe)
#define TRIGGER_PIN       13

#define UART_BAUD         115200

// Built-in flash LED
#define FLASH_LED_PIN     4

// ==================== GLOBAL VARIABLES ====================
const char* ssid = "cybergenii";
const char* password = "12341234";
const char* backend_url = "https://xenophobic-netta-cybergenii-1584fde7.koyeb.app";
const char* local_access_password = "SmartBin2025";

WebSocketsServer webSocket(81);
AsyncWebServer server(80);

// ==================== ESP-NOW VARIABLES ====================
// ESP32 Main MAC Address - WILL BE AUTO-DETECTED
uint8_t mainControllerMAC[6];
bool mainControllerRegistered = false;
bool espNowInitialized = false;

// ESP-NOW Message Structures (must match ESP32 Main)
typedef struct {
  char command[32];
  unsigned long timestamp;
} CommandMessage;

typedef struct {
  char material[32];
  float confidence;
  unsigned long timestamp;
} DetectionResult;

// ==================== STATE VARIABLES ====================
volatile bool detectionRequested = false;
String lastDetectedMaterial = "UNKNOWN";
float lastConfidence = 0.0;
unsigned long lastDetectionTime = 0;
unsigned long bootTime = 0;

// Statistics
int totalDetections = 0;
int wirelessTriggers = 0;
int gpioTriggers = 0;
int wirelessResponses = 0;
int uartResponses = 0;

// ==================== FUNCTION DECLARATIONS ====================
void setupCamera();
void setupWiFi();
void setupESPNow();
void setupWebServer();
void setupUART();
void IRAM_ATTR triggerISR();
void detectMaterial();
void sendToBackend(uint8_t* image, size_t len);
void sendUARTResult(String material, float confidence);
void sendESPNowResult(String material, float confidence);
void webSocketEvent(uint8_t num, WStype_t type, uint8_t * payload, size_t length);
bool authenticateRequest(AsyncWebServerRequest *request);
void onDataRecv(const uint8_t *mac, const uint8_t *incomingData, int len);
void onDataSent(const uint8_t *mac, esp_now_send_status_t status);
void flashLED(int times);

// ==================== SETUP ====================
void setup() {
  Serial.begin(115200);
  delay(1000);
  
  bootTime = millis();
  
  Serial.println("\n\n=================================");
  Serial.println("ESP32-CAM Material Detection");
  Serial.println("ESP-NOW Wireless + Backup GPIO/UART");
  Serial.println("=================================");
  
  // Initialize flash LED
  pinMode(FLASH_LED_PIN, OUTPUT);
  digitalWrite(FLASH_LED_PIN, LOW);
  
  // Flash LED on boot
  flashLED(3);
  
  // Initialize Camera FIRST
  setupCamera();
  
  // Initialize WiFi
  setupWiFi();
  
  // Print MAC address for pairing
  Serial.print("\n📍 ESP32-CAM MAC Address: ");
  Serial.println(WiFi.macAddress());
  Serial.println("   → Add this to ESP32 Main's camMacAddress[]");
  
  // Initialize ESP-NOW
  setupESPNow();
  
  // Initialize UART (backup)
  setupUART();
  
  // Initialize Web Server
  setupWebServer();
  
  // Initialize WebSocket
  webSocket.begin();
  webSocket.onEvent(webSocketEvent);
  
  // Setup trigger pin (GPIO 13 - boot-safe)
  pinMode(TRIGGER_PIN, INPUT_PULLUP);
  attachInterrupt(digitalPinToInterrupt(TRIGGER_PIN), triggerISR, RISING);
  
  Serial.println("\n=================================");
  Serial.println("ESP32-CAM READY");
  Serial.println("=================================");
  Serial.print("Local IP: ");
  Serial.println(WiFi.localIP());
  
  Serial.println("\n📡 Communication Status:");
  Serial.println("  ESP-NOW: " + String(espNowInitialized ? "✅ Active" : "❌ Failed"));
  Serial.println("  GPIO Trigger: ✅ Active (GPIO 13)");
  Serial.println("  UART TX: ✅ Active (GPIO 14)");
  
  Serial.println("\n📍 Pin Configuration:");
  Serial.printf("  UART TX: GPIO%d → ESP32 Main GPIO15\n", UART_TX_PIN);
  Serial.printf("  Trigger: GPIO%d ← ESP32 Main GPIO4\n", TRIGGER_PIN);
  
  Serial.println("\n🎥 Waiting for detection trigger...");
  Serial.println("=================================\n");
  
  // Send ready signal
  delay(500);
  sendESPNowResult("SYSTEM_READY", 1.0);
  sendUARTResult("SYSTEM_READY", 1.0);
}

// ==================== MAIN LOOP ====================
void loop() {
  webSocket.loop();
  
  if (detectionRequested) {
    detectionRequested = false;
    
    // Debounce
    if (millis() - lastDetectionTime > 1000) {
      Serial.println("\n>>> DETECTION TRIGGERED <<<");
      detectMaterial();
      lastDetectionTime = millis();
      totalDetections++;
    }
  }
  
  delay(10);
}

// ==================== INTERRUPT HANDLER ====================
void IRAM_ATTR triggerISR() {
  detectionRequested = true;
  gpioTriggers++;
}

// ==================== ESP-NOW SETUP ====================
void setupESPNow() {
  Serial.println("\nInitializing ESP-NOW...");
  
  // Init ESP-NOW
  if (esp_now_init() != ESP_OK) {
    Serial.println("  ❌ ESP-NOW init failed");
    espNowInitialized = false;
    return;
  }
  
  espNowInitialized = true;
  Serial.println("  ✓ ESP-NOW initialized");
  
  // Register callbacks
  esp_now_register_send_cb(onDataSent);
  esp_now_register_recv_cb(onDataRecv);
  
  Serial.println("  ✓ Callbacks registered");
  Serial.println("  → Waiting for ESP32 Main to pair...");
}

// ==================== ESP-NOW CALLBACKS ====================
void onDataSent(const uint8_t *mac, esp_now_send_status_t status) {
  if (status == ESP_NOW_SEND_SUCCESS) {
    Serial.println("📡 ESP-NOW: Send ✅ Success");
    wirelessResponses++;
  } else {
    Serial.println("📡 ESP-NOW: Send ❌ Failed");
    // Fallback to UART
    Serial.println("  → Using UART fallback");
  }
}
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

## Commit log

2025-10-29 feat: add full Flutter project scaffold for smart_bin_app (macOS, Windows, Web, tests, design)
    - Add Flutter app metadata and dependencies
    - pubspec.yaml (name: smart_bin_app, version: 1.0.0+1, flutter + cupertino_icons)
    - pubspec.lock generated with resolved package versions
    - macOS platform support
    - macOS Runner project files and configs:
    - Runner Xcode assets & icons (app_icon_16/32/64/128/256/512.png)
    - MainMenu.xib and Info.plist
    - AppInfo.xcconfig, Debug.xcconfig, Release.xcconfig, Warnings.xcconfig
    - Release.entitlements, DebugProfile.entitlements
    - MainFlutterWindow.swift and RunnerTests.swift
    - Added macOS app bundle configuration (PRODUCT_NAME, bundle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
    [smart_bin_design.kicad_pcb, smart_bin_design.kicad_sch]
2025-10-29 feat(kicad): add KiCad project files and defaults for smart_bin_design
    - populate smart_bin_design.kicad_pro with board design defaults, DRC rule severities, teardrop/teardrop parameters, tuning patterns, netclasses and PCB metadata
    - add smart_bin_design.kicad_prl (layout/session preferences)
    - add fp-info-cache and project backup archive
    - remove stale PCB lock file (~smart_bin_design.kicad_pcb.lck)
2025-11-05 chore: remove outdated SETUP_GUIDE.md
    - Deleted the SETUP_GUIDE.md file as it is no longer relevant to the project documentation.
    - This cleanup helps streamline the documentation and focus on more current resources.
2025-11-05 chore: clean up README by removing outdated notes
    - Removed obsolete notes regarding material detection, CAN communication, storage, and servo calibration from README.md to streamline documentation and focus on relevant information for users.
2026-01-31 feat: Add PlatformIO library dependencies and generated build artifacts.
    [smart_bin_design.kicad_sch, smart_waste_circuitry.kicad_pcb, smart_waste_circuitry.kicad_sch]
2026-01-31 feat: Introduce ultrasonic level sensors for organic and inorganic bins, updating pinouts, firmware, and backend data models.
2026-01-31 chore: Remove temporary KiCad auto-save and lock files.
2026-02-04 feat: integrate Gemini API for waste material classification, update dependencies, and configure project environment.
2026-02-11 feat: Implement ESP-NOW communication for camera, update ultrasonic sensor logic, refactor pin assignments, and add LED test/chase mode.
2026-02-14 feat: migrate firmware servo control to PCA9685 driver and improve ultrasonic sensor readings and backend command polling
2026-02-15 feat: Enhance detection flow in the app by adding detection status management, recent detection polling, and improved WebSocket message handling for material analysis and bin operations.
2026-02-15 feat: Add devices router and system status endpoint; enhance alert handling with Telegram notifications and improve timestamp formatting for API responses.
2026-02-19 feat: Add ESP32 command acknowledgment, display device connection status in the app, and adjust simulation polling frequency.
